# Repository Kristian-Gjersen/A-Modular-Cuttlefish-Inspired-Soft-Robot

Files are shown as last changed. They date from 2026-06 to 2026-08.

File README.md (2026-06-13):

# CUTTLE-DROID

<div align="center">
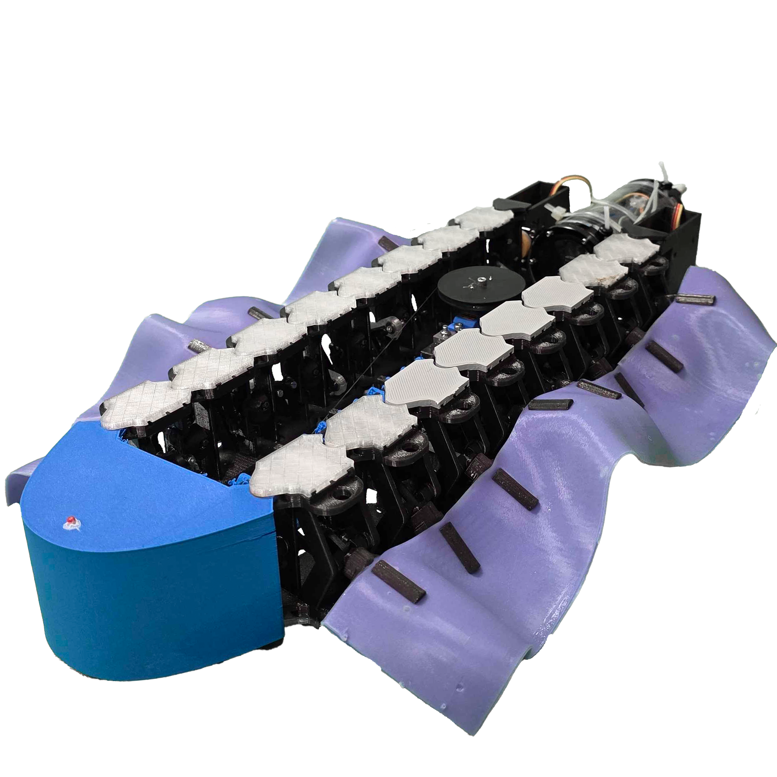
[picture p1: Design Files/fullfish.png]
  
</div>

C.U.T.T.L.E.-D.R.O.I.D.: Cuttlefish-Inspired Underwater Technology for Terrain Locomotion &amp; Exploration – Drone Robot for Ocean Inspection &amp; Discovery (Cuttle-Droid)

This repository contains the control code, setup code, 3D STL files and further supplementary used for the development of the **Cuttle-Droid** - a modular cuttlefish bio-inspired soft robot that mimics undulating wave-like motion for locomotion.

## Repository Structure

```
A-Modular-Cuttlefish-Inspired-Soft-Robot/
│
├── Design-Files/                    # Mechanical design files
│   ├── Mold/                        # STL files for casting fin
│   └── Robot/                       # STL files for the robot
│       └──Assembly-Guide/           # PDF guide on robot assembly
│
└── Robot-Control-Code/              # Arduino code for the main robot controller and pyhon code for remote control
    ├── RobotControlCode.ino         # Main controller logic For the robot
    ├── RobotRemoteController.py     # Remote controller script for manual steering
    └── Force_Test.py                # Python code for remotely controlling the force tests.
```

## Hardware Requirements
 - ESP32C3 microcontroller
 - Motor drivers and actuators
 - loadcell force sensor
 - hotspot or wifi access

## Software Requirements
- [Arduino IDE](https://www.arduino.cc/en/software)
- Python 3.11+ with packages:
    - `matplotlib`, `serial`, `keyboard`, `csv`, `time`, `socket`, `numpy`, `os`, `nidaqmx`

## Design Files

### Robot Parts
- All STL files for robot assembly located in `Design-Files/Robot`
- Guide for robot assembly and part count located in `Design-Files/Robot/Assembly-Guide`

### Mold
- STL files for Mold for fin casting found in `Design-Files/Mold`

## Code files
- `RobotControlCode.ino` contains the code uploaded to the robot. This code automatically start connecting to the provided hotspot and awaits requests for actuator inputs.
- `RobotRemoteController.py` contains the controller code for the controlling laptop. This code will start searching for ESP32 on the hotspot and once connected it will allow for sending inputs to control the actuators on the robot. Always turn on the robot before starting this script. The controls works as follows:
```
W = speed up forward
S = slow down
A/D = soft turn left and right
Q/E = servo steering left and right
Z/C = differential turn left and right
SPACE = stop
```
- `Force_Test.py` contains the script used for doing force test readings on the robot. It sets up the ESP32, Daq, and Arduino to automatically perform the test that is selected. It will handle timing and duty cycle inputs to the robot. Always have the robot turned on before performing force test.

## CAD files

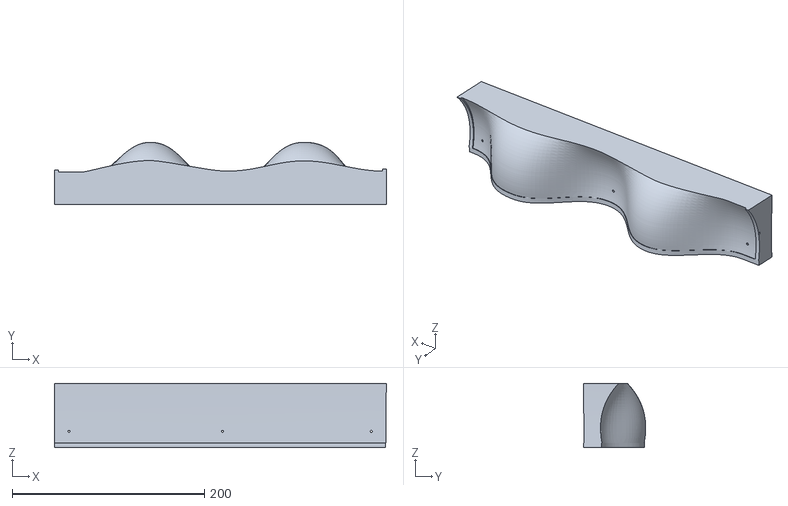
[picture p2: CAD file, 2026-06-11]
Design Files/Mold/Mold 1.stl
345.8 x 65.0 x 67.0

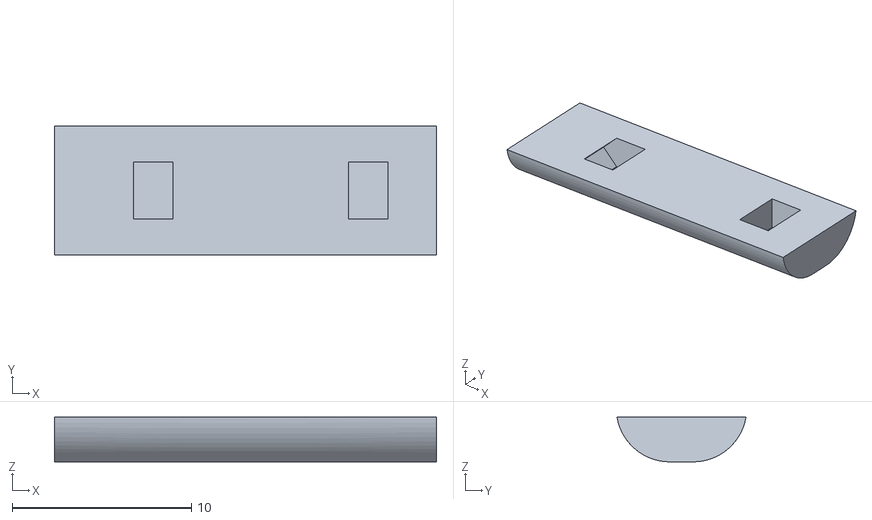
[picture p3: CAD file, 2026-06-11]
Design Files/Robot/Pocket Fin Clamp.stl
21.3 x 7.20 x 2.50

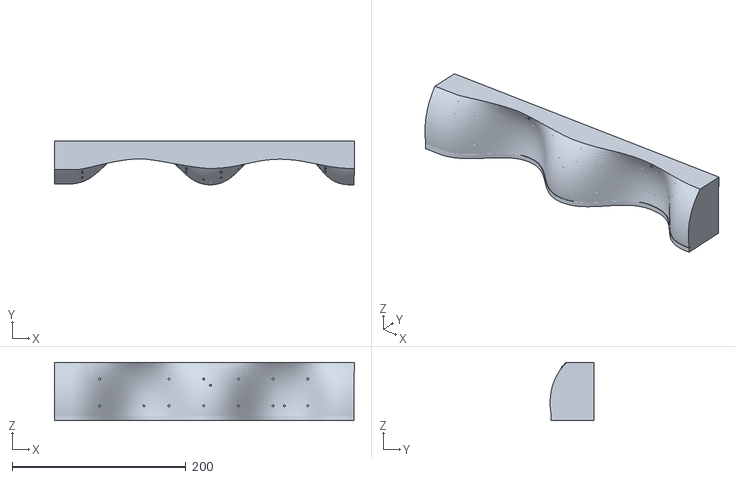
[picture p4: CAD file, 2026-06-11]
Design Files/Mold/Mold 2.stl
345.8 x 50.4 x 67.0

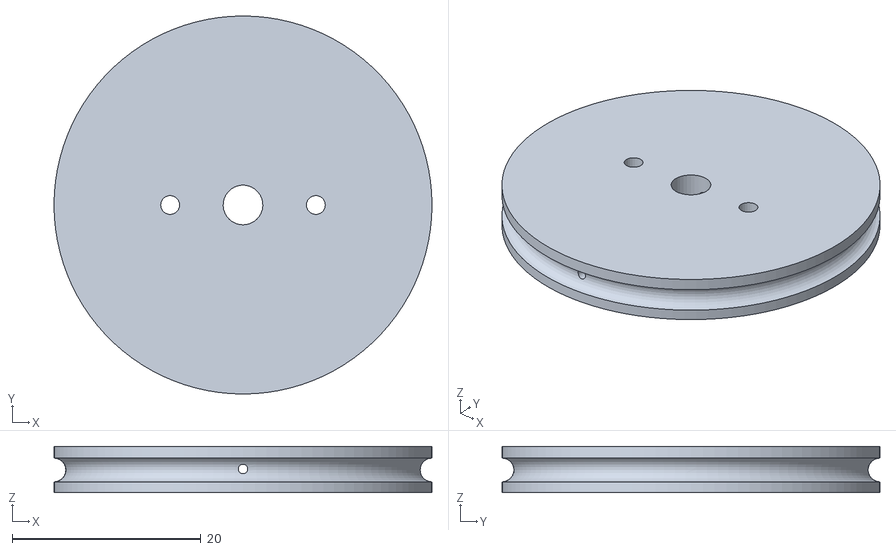
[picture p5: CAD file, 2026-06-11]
Design Files/Robot/Thread Holder.stl
40.0 x 40.0 x 4.90

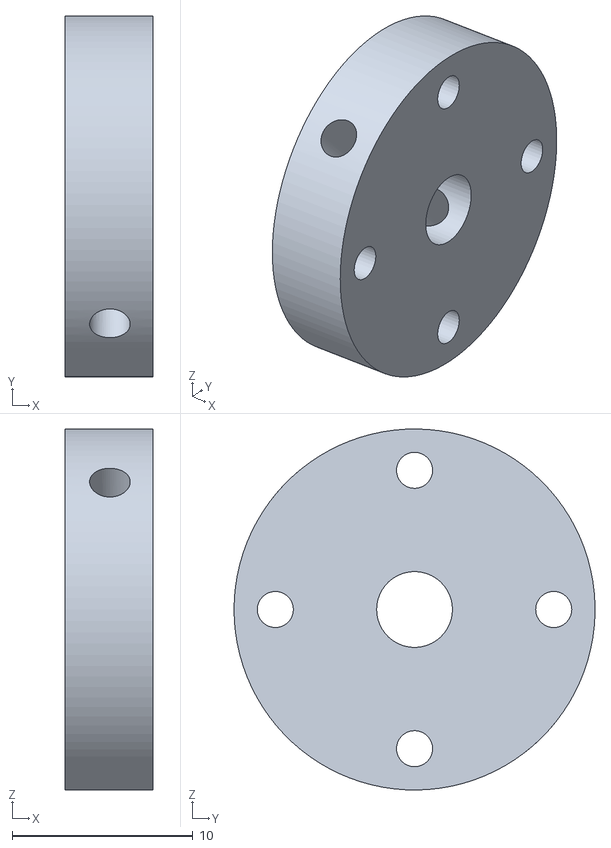
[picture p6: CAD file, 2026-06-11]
Design Files/Robot/Servo Ball Joint.stl
4.90 x 20.0 x 20.0

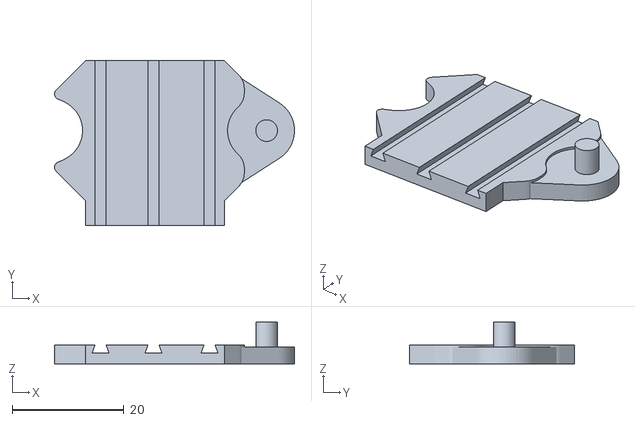
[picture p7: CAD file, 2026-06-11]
Design Files/Robot/Clamp.stl
43.0 x 29.6 x 7.50

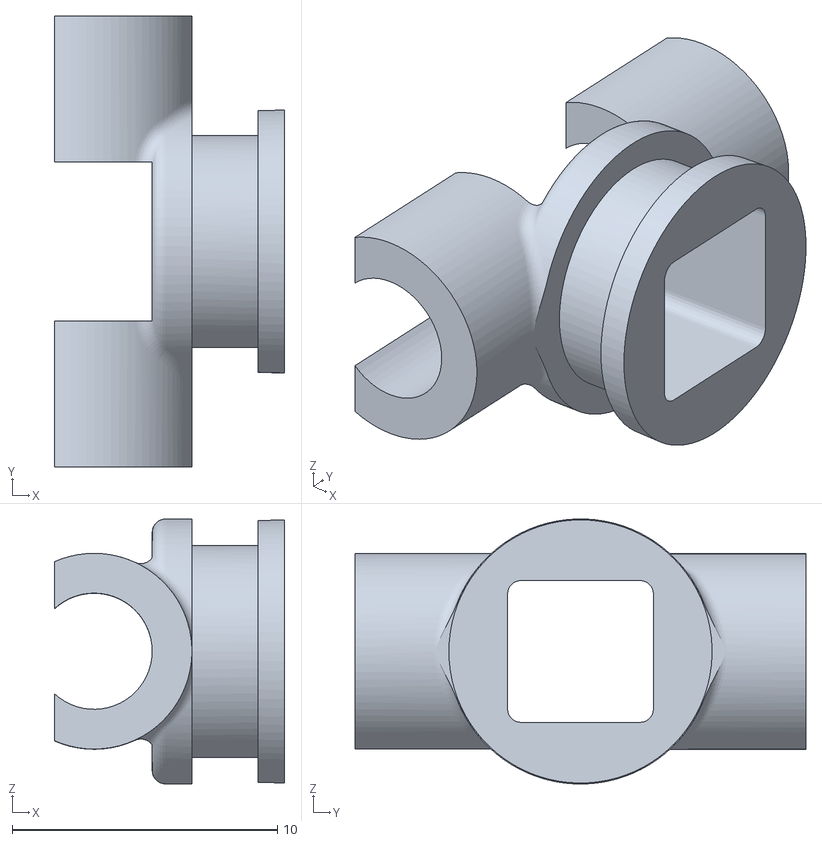
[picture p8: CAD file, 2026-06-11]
Design Files/Robot/Pocket Sleeve Joint.stl
8.69 x 17.0 x 10.00

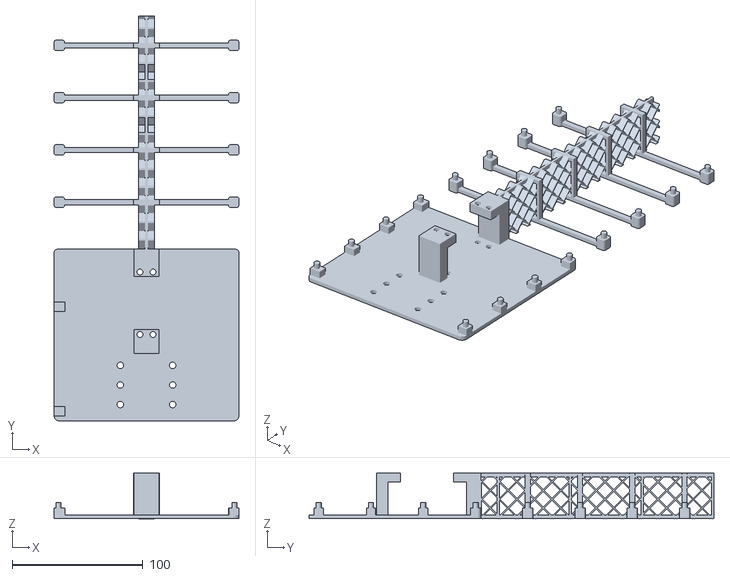
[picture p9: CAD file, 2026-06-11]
Design Files/Robot/Spine.stl
141.5 x 310.0 x 35.2

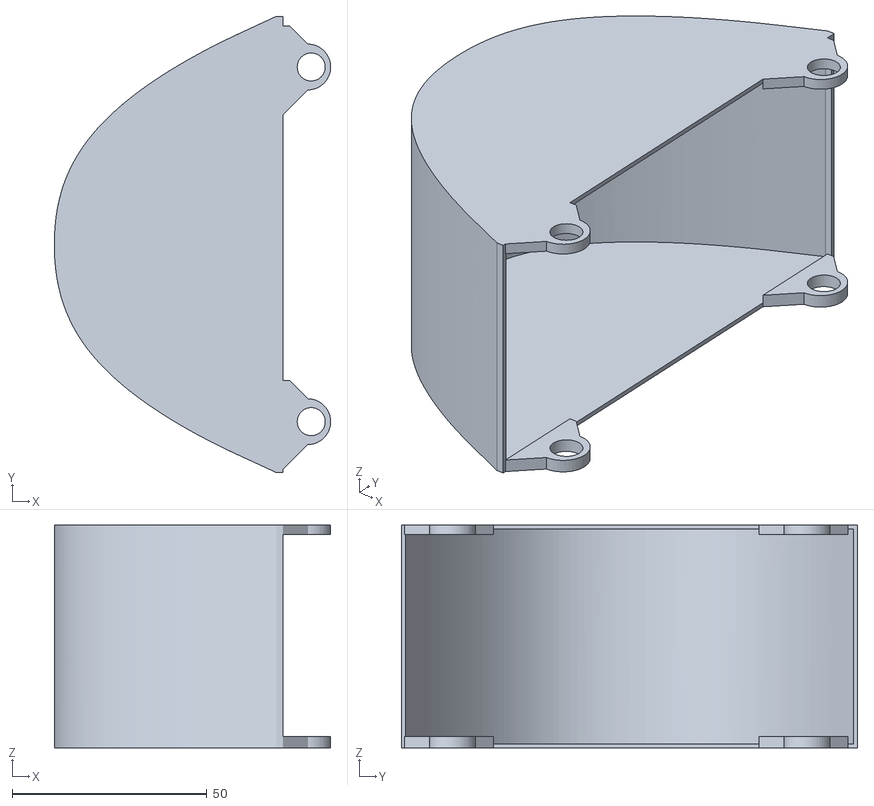
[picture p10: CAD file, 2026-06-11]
Design Files/Robot/Head.stl
70.9 x 117.0 x 57.2

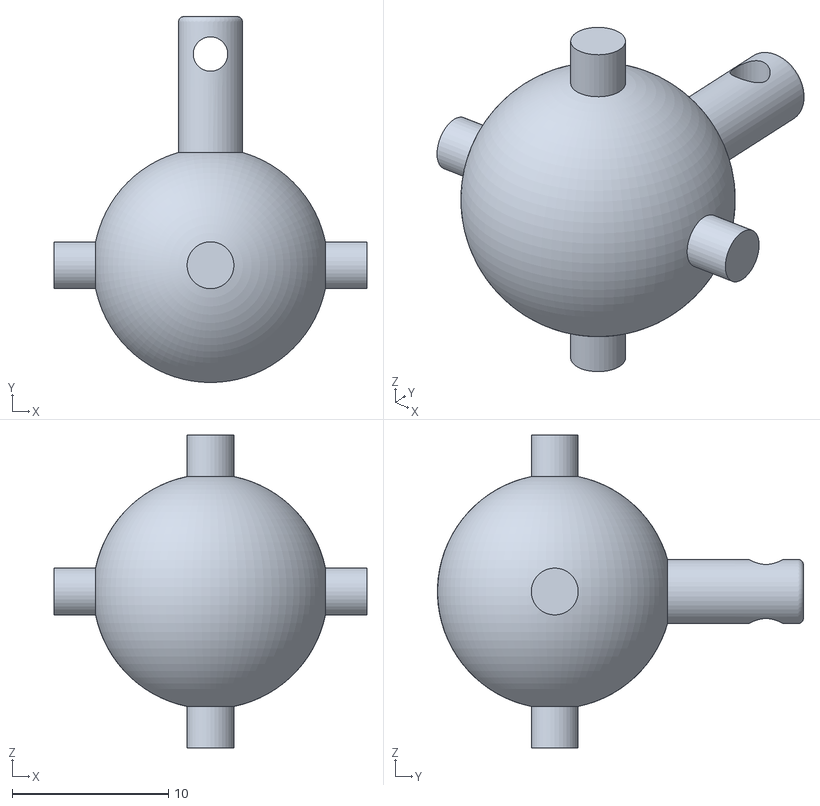
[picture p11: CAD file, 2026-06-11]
Design Files/Robot/Camshaft Ball.stl
20.0 x 23.4 x 20.0

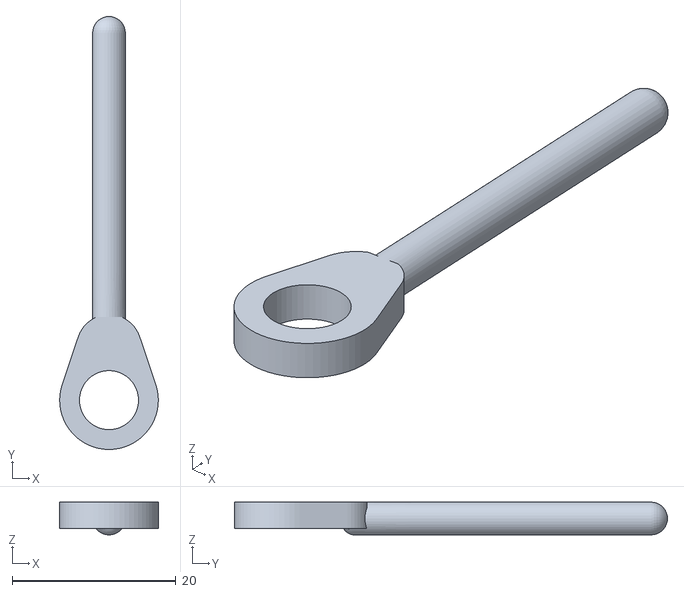
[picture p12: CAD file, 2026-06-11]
Design Files/Robot/Rod.stl
12.0 x 52.8 x 4.00

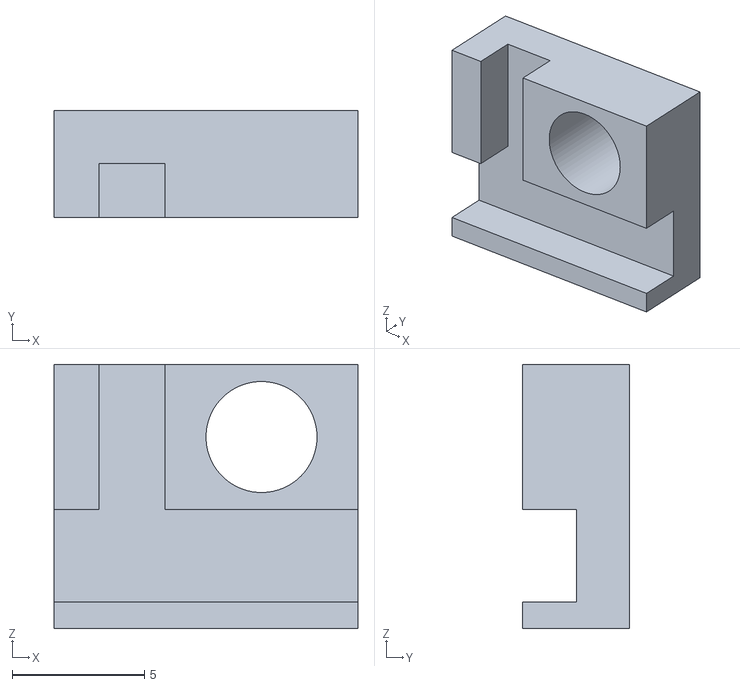
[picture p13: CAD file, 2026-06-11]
Design Files/Robot/Tendon Holder Part 1.stl
11.5 x 4.05 x 10.0

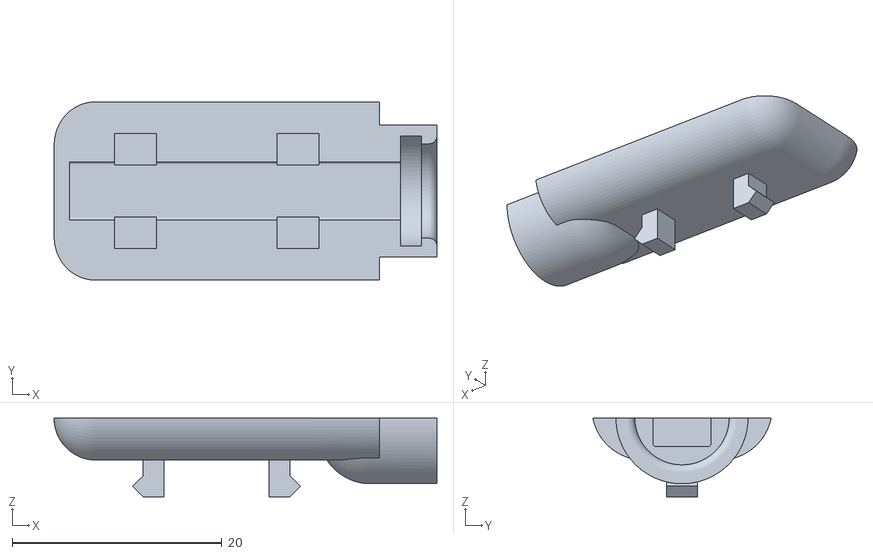
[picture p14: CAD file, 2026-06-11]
Design Files/Robot/Pocket Top.stl
36.5 x 17.0 x 7.50

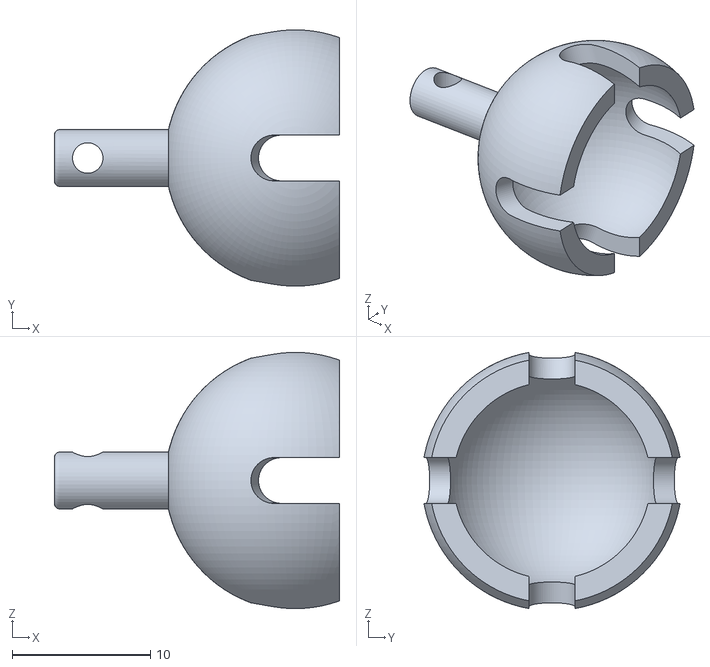
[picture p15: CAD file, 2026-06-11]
Design Files/Robot/Camshaft Cup.stl
20.6 x 18.5 x 18.5

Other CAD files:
Design Files/Robot/Motor Holder.stl
Design Files/Robot/Motor Clamp Top.stl
Design Files/Robot/Camshaft Spacer.stl
Design Files/Robot/Pocket Bottom.stl
Design Files/Robot/Camshaft Bottom.stl
Design Files/Robot/Clamp Mirrored.stl
Design Files/Robot/Dovetail Pin.stl
Design Files/Robot/Frame.stl
Design Files/Robot/Motor Clamp Bottom.stl
Design Files/Robot/Tendon Holder Part 2.stl

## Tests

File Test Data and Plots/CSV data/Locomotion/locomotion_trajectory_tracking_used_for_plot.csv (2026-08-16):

 | mass_A
x | y
3.591918E-1 | -1.433480E-1
3.635274E-1 | -1.420296E-1
3.674668E-1 | -1.415576E-1
3.711204E-1 | -1.419468E-1
3.733004E-1 | -1.457875E-1
3.748996E-1 | -1.497346E-1
3.763999E-1 | -1.533793E-1
3.784218E-1 | -1.570687E-1
3.804790E-1 | -1.590580E-1
3.815482E-1 | -1.605636E-1
3.828061E-1 | -1.604650E-1
3.831343E-1 | -1.597268E-1
3.832537E-1 | -1.589973E-1
3.834170E-1 | -1.590138E-1
3.833947E-1 | -1.581930E-1
3.832934E-1 | -1.574010E-1
3.835377E-1 | -1.576304E-1
3.836087E-1 | -1.571106E-1
3.837571E-1 | -1.564713E-1
3.836312E-1 | -1.560985E-1
3.838335E-1 | -1.548110E-1
3.849036E-1 | -1.535936E-1
3.855755E-1 | -1.534003E-1
3.857027E-1 | -1.525668E-1
3.864230E-1 | -1.515214E-1
3.876199E-1 | -1.508585E-1
3.891273E-1 | -1.488150E-1
3.907098E-1 | -1.477049E-1
3.919873E-1 | -1.478055E-1
3.936036E-1 | -1.472316E-1
3.966411E-1 | -1.460089E-1
3.994982E-1 | -1.451338E-1
4.025773E-1 | -1.426647E-1
4.059409E-1 | -1.416462E-1
4.094240E-1 | -1.384673E-1
4.122796E-1 | -1.357946E-1
4.150008E-1 | -1.336879E-1
4.177148E-1 | -1.332203E-1
4.200919E-1 | -1.338718E-1
4.223962E-1 | -1.357766E-1
4.248015E-1 | -1.362407E-1
4.263255E-1 | -1.374444E-1
4.276979E-1 | -1.377233E-1
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

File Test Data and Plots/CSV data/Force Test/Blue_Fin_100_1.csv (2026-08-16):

time | voltage | force_N
0.000000000000000000e+00 | 3.627415765076875687e-01 | 1.613554921375166540e-01
1.000000000000000021e-03 | 3.470953628420829773e-01 | 1.543957095550839709e-01
2.000000000000000042e-03 | 3.366645537316799164e-01 | 1.497558545001288766e-01
3.000000000000000062e-03 | 3.262337446212768555e-01 | 1.451159994451737545e-01
4.000000000000000083e-03 | 3.158029355108737946e-01 | 1.404761443902186602e-01
5.000000000000000104e-03 | 3.105875309556722641e-01 | 1.381562168627410991e-01
6.000000000000000125e-03 | 3.105875309556722641e-01 | 1.381562168627410991e-01
7.000000000000000146e-03 | 3.001567218452692032e-01 | 1.335163618077860048e-01
8.000000000000000167e-03 | 2.949413172900676727e-01 | 1.311964342803084438e-01
8.999999999999999320e-03 | 2.897259127348661423e-01 | 1.288765067528308828e-01
1.000000000000000021e-02 | 2.897259127348661423e-01 | 1.288765067528308828e-01
1.099999999999999936e-02 | 2.897259127348661423e-01 | 1.288765067528308828e-01
1.200000000000000025e-02 | 2.845105081796646118e-01 | 1.265565792253533217e-01
1.299999999999999940e-02 | 2.740796990692615509e-01 | 1.219167241703982552e-01
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

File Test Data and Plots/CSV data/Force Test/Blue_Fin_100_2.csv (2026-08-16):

time | voltage | force_N
0.000000000000000000e+00 | -6.492159701883792877e-02 | -2.887856511564265358e-02
1.000000000000000021e-03 | -8.578321523964405060e-02 | -3.815827522555285956e-02
2.000000000000000042e-03 | -1.118602380156517029e-01 | -4.975791286294062310e-02
3.000000000000000062e-03 | -1.275064516812562943e-01 | -5.671769544537327845e-02
4.000000000000000083e-03 | -1.431526653468608856e-01 | -6.367747802780593380e-02
5.000000000000000104e-03 | -1.587988790124654770e-01 | -7.063726061023860303e-02
6.000000000000000125e-03 | -1.796604972332715988e-01 | -7.991697072014880554e-02
7.000000000000000146e-03 | -2.161683291196823120e-01 | -9.615646341249167728e-02
8.000000000000000167e-03 | -2.422453518956899643e-01 | -1.077561010498794269e-01
8.999999999999999320e-03 | -2.631069701164960861e-01 | -1.170358111597896295e-01
1.000000000000000021e-02 | -2.839685883373022079e-01 | -1.263155212696998320e-01
1.099999999999999936e-02 | -3.048302065581083298e-01 | -1.355952313796100484e-01
1.200000000000000025e-02 | -3.204764202237129211e-01 | -1.425550139620427037e-01
1.299999999999999940e-02 | -3.413380384445190430e-01 | -1.518347240719528923e-01
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

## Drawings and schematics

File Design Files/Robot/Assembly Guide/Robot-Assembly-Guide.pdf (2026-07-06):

# Cuttle Bot

## User assembly manual for 8 links Cuttle bot

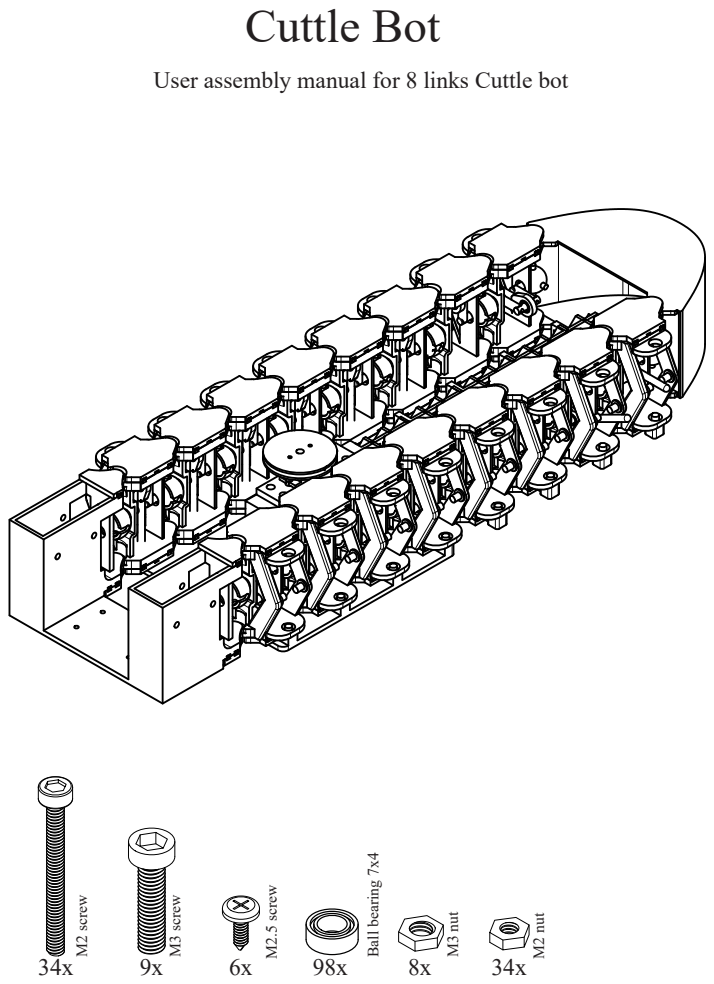
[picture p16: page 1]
34x M² screw; M3 screw; M2.5 screw; Ball bearing 7x4; M3 nut; M2 nut

# One 8 Link Propulsion Module assembly

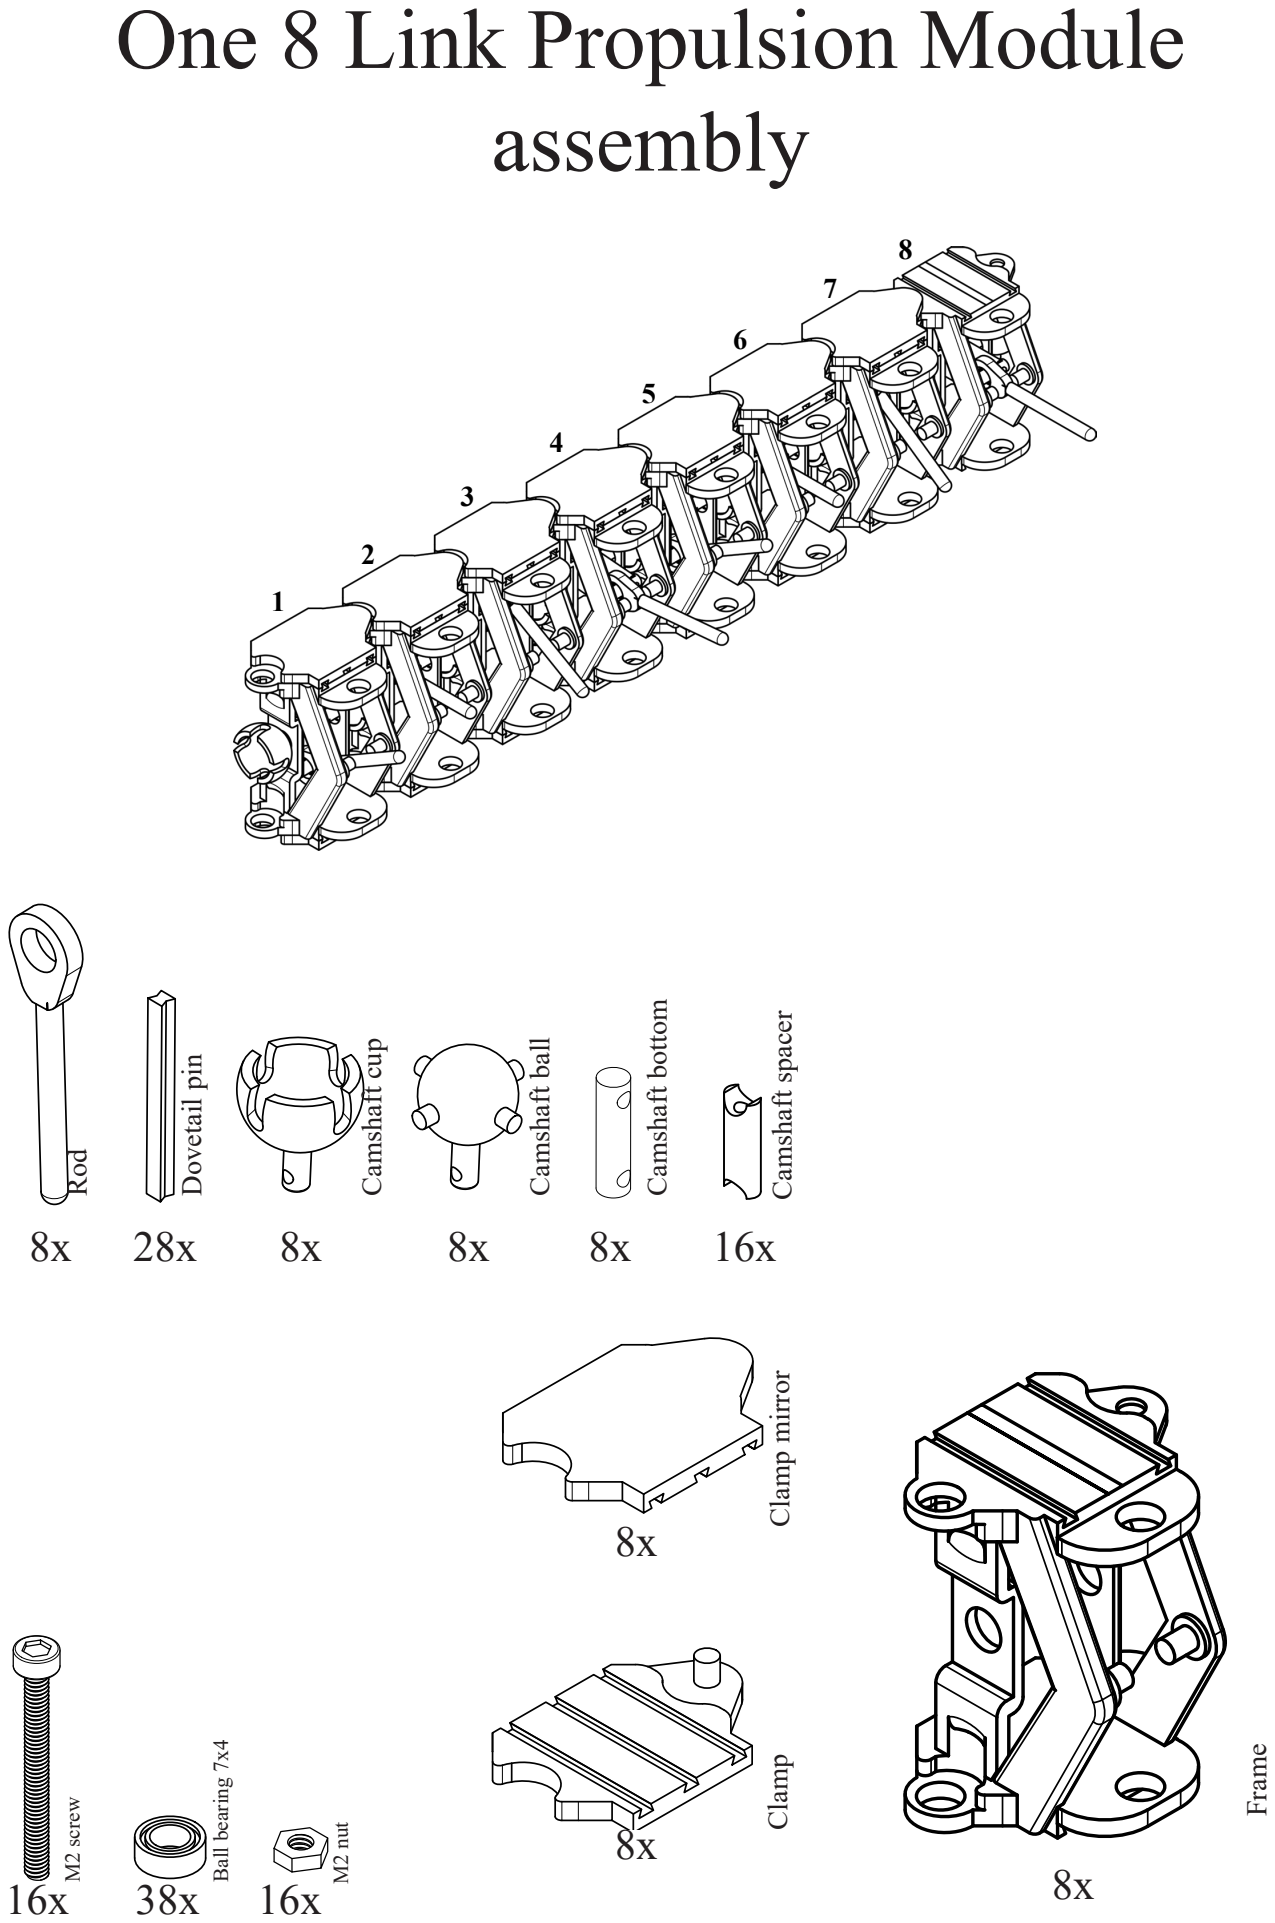
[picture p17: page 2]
Created by; Document type; Approved by; Document status; Camshaft Bottom; Rod; Dovetail pin; Camshaft cup; Camshaft ball; Camshaft bottom; Camshaft spacer; 16x 38x 16x M² screw; Ball bearing 7x4; M2 nut; Frame

Rikke Thastum Joergensen

Title DWG No.

Rev. Date of issue

Clamp Clamp mirror

1 | 2

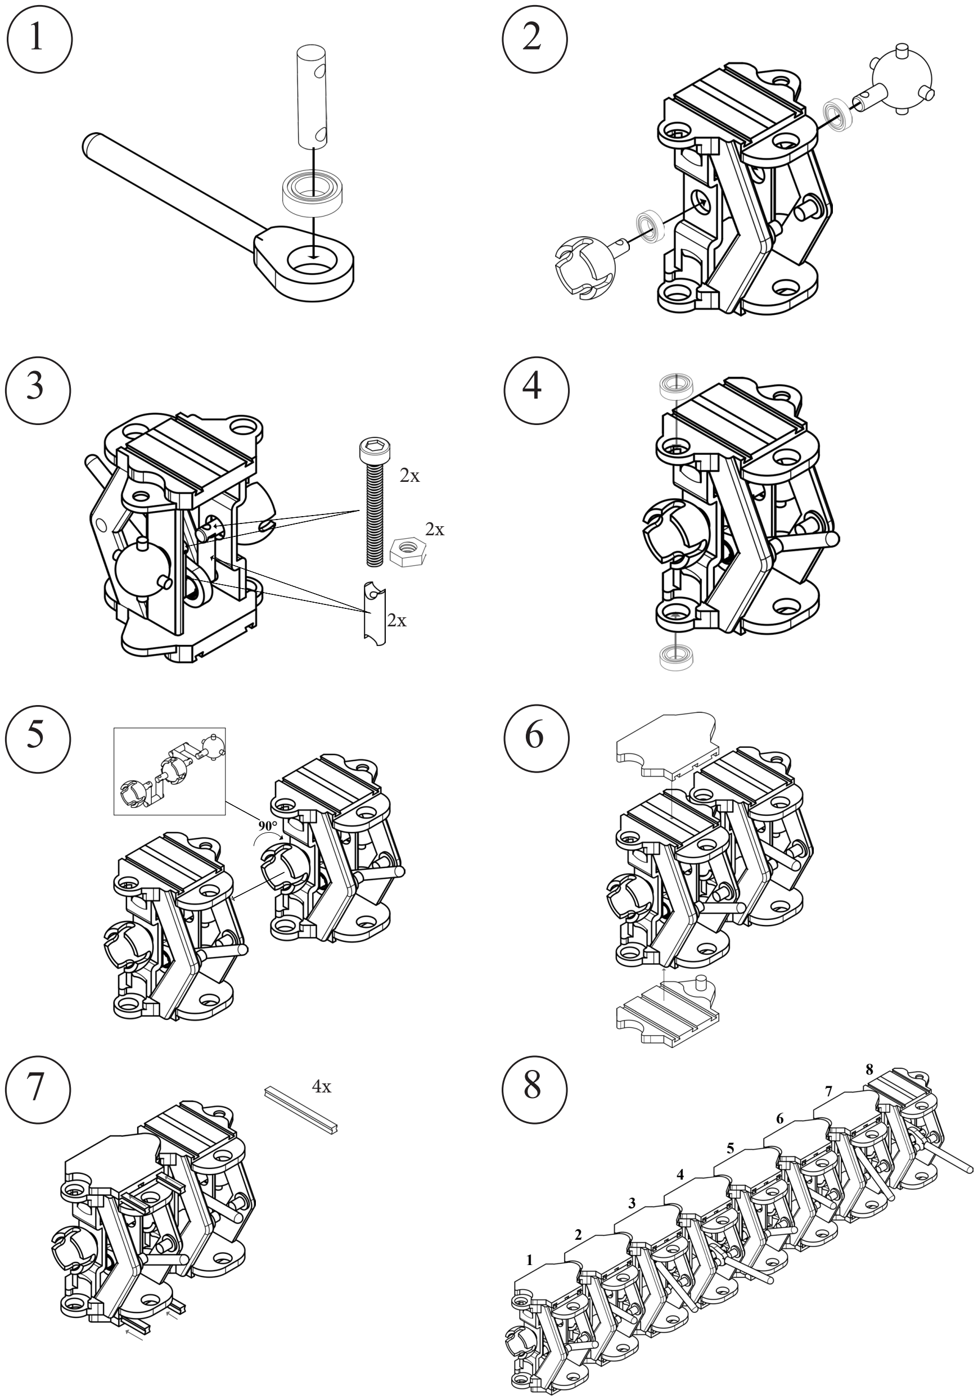
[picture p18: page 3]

90°

2x

2x

4x

3 | 4
5 | 6

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
# Steering Module assembly

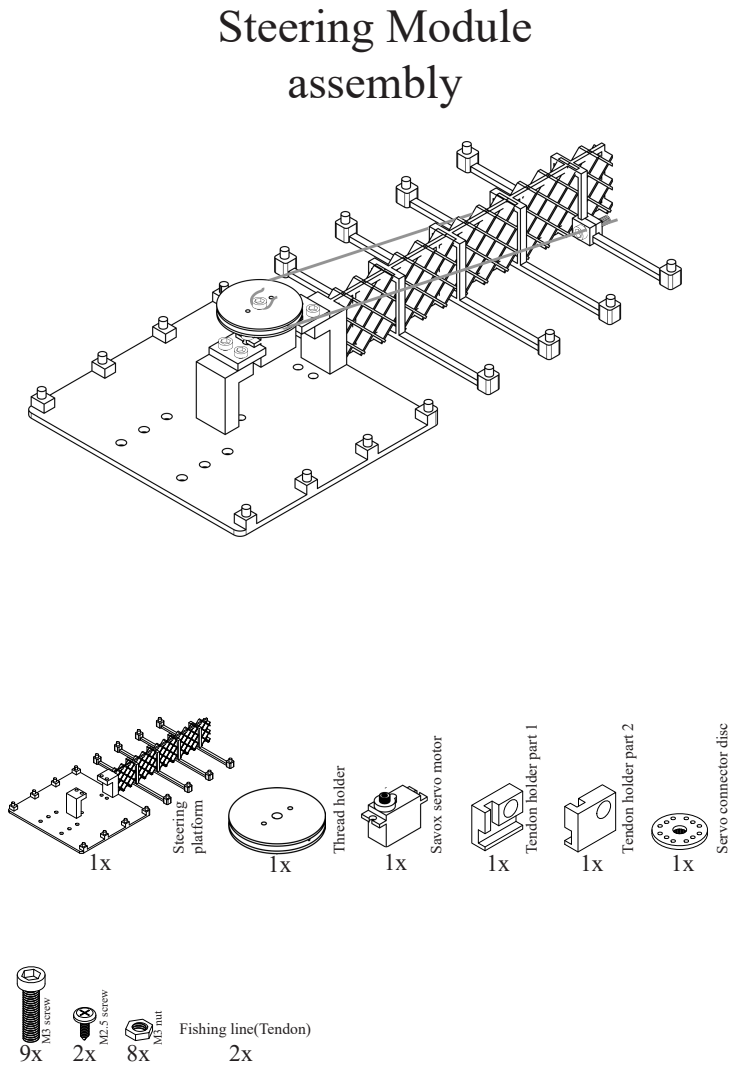
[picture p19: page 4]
Steering; platform; Thread holder; M3 screw; M2.5 screw

Tendon holder part 1

Tendon holder part 2

Servo connector disc

Savox servo motor

M3 nut
Fishing line(Tendon)

1

2

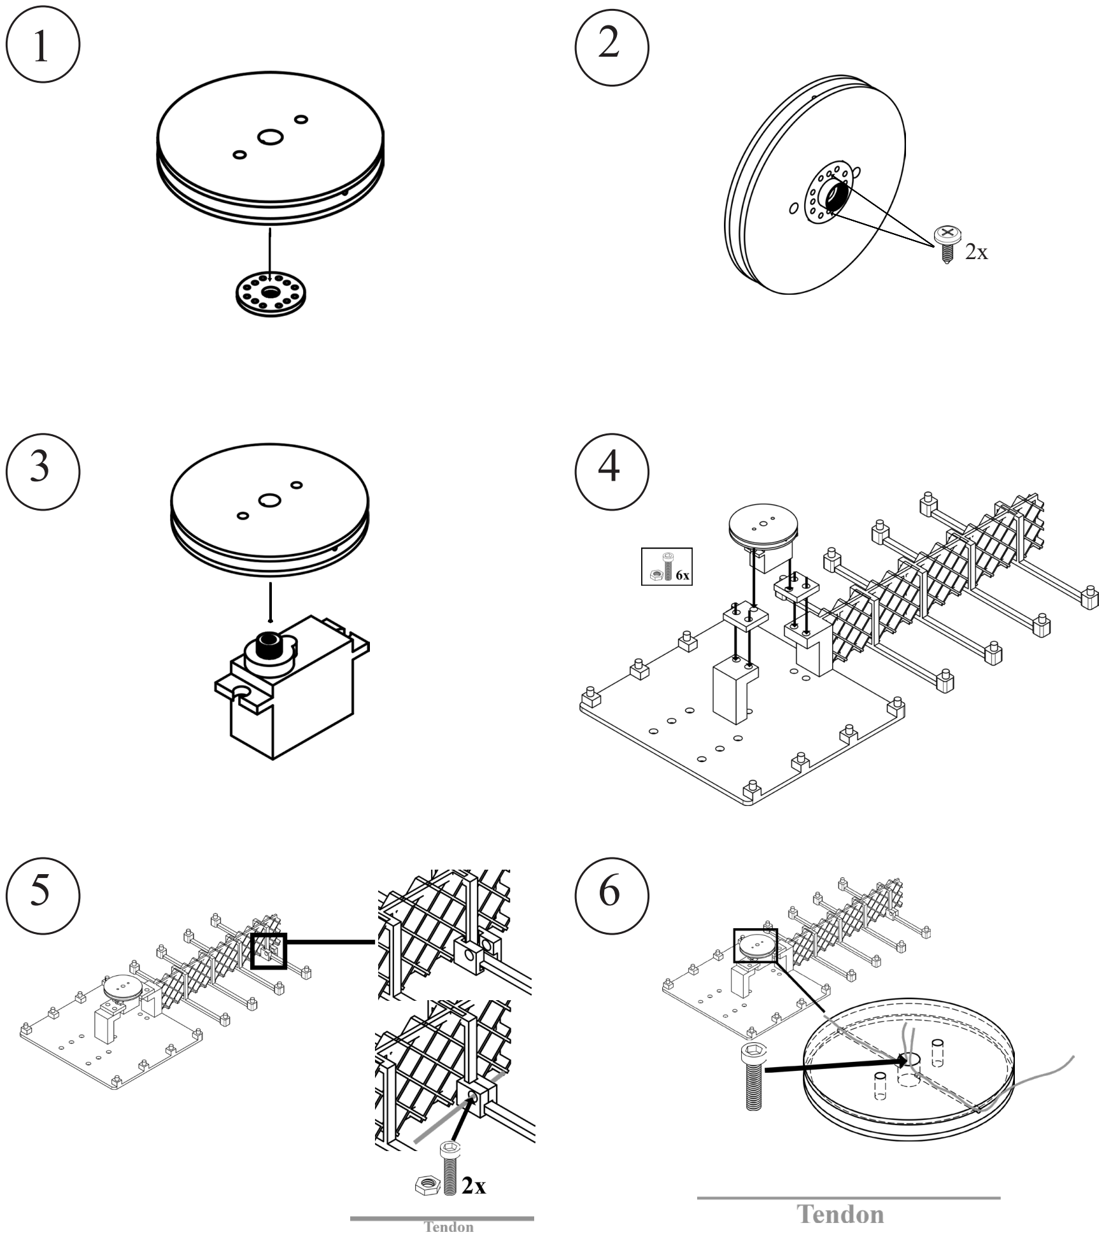
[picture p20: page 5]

3

4

5

6

2x

# Camshaft Motor Module assembly

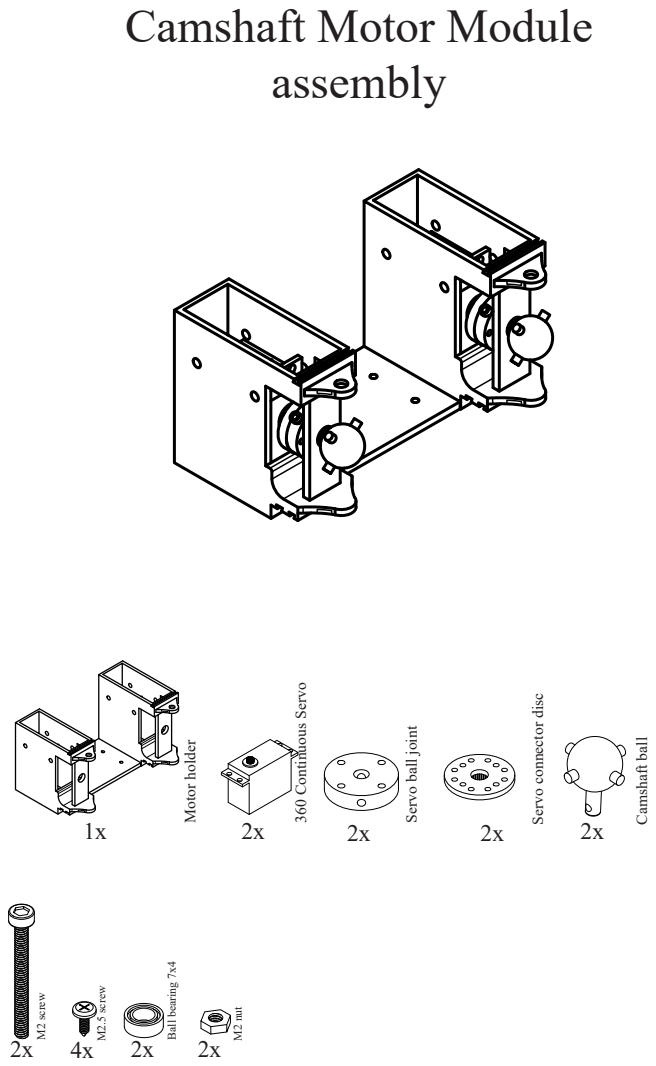
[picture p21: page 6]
2x M² screw; Ball bearing 7x4; M2 nut; Motor holder; 360 Continuous Servo; Created by; Document type; M2.5 screw

Rikke Thastum Joergensen Camshaft ball

Servo connector disc

Servo ball joint

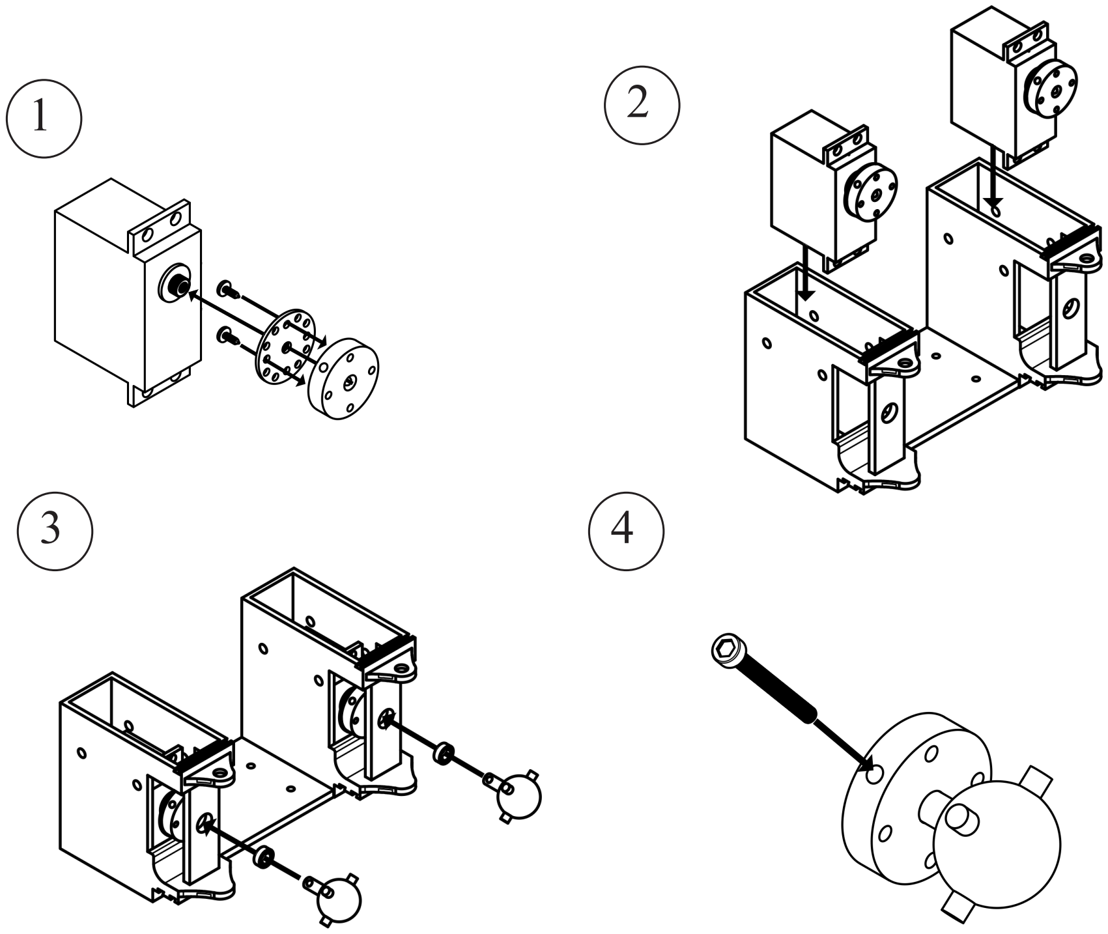
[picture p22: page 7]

1

2

3

4

# Complete assembly

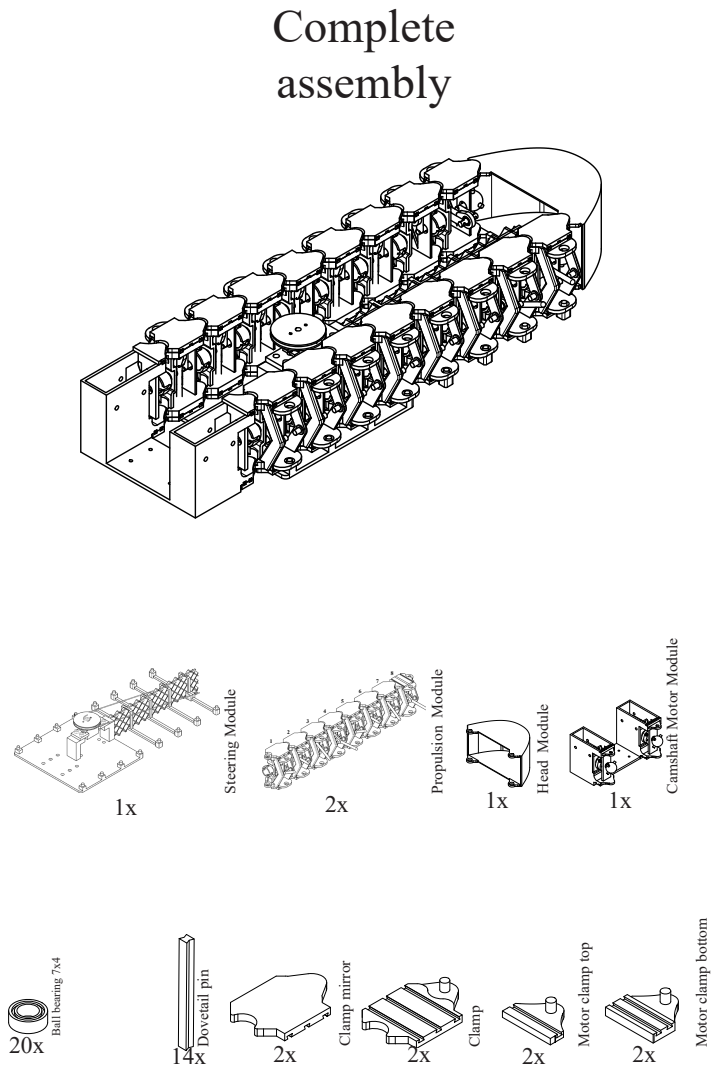
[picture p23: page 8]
Ball bearing 7x4; Steering Module; Propulsion Module; Head Module; Clamp mirror; Clamp; Dovetail pin

Camshaft Motor Module

Motor clamp bottom

Motor clamp top

1 | 2

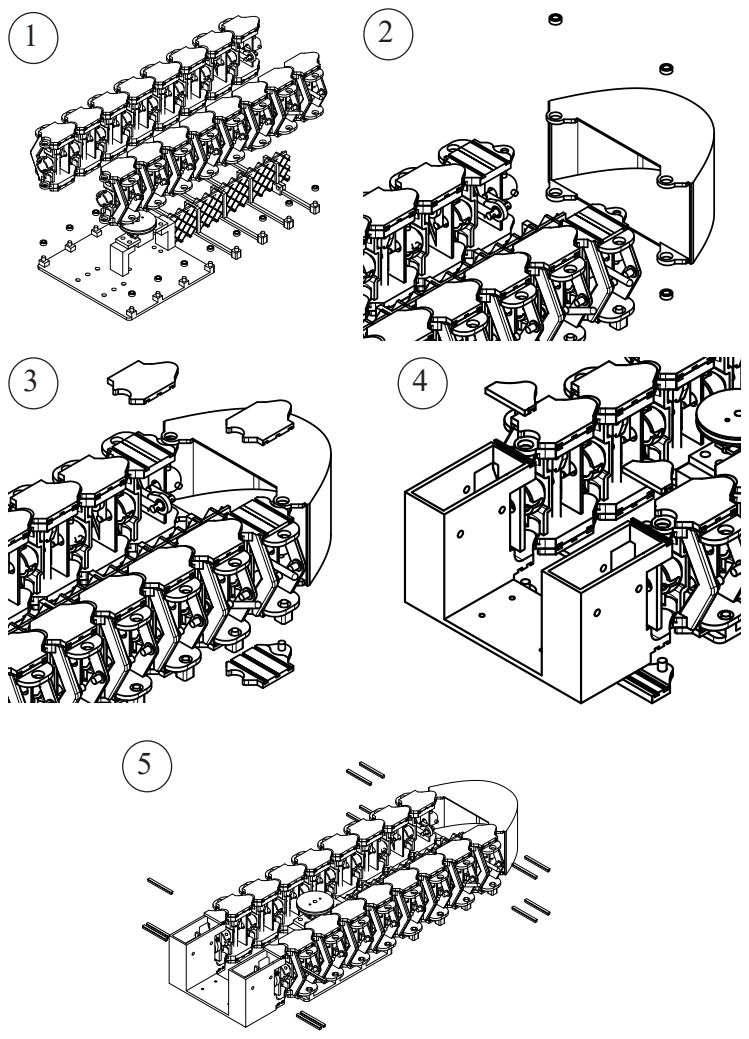
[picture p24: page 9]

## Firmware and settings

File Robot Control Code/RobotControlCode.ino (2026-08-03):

#include <WiFi.h>
#include <Wire.h>
#include <Adafruit_PWMServoDriver.h>

// WiFi
// ----
// Setup a costum hotspot and provide ssid and password
// Make sure that the laptop is connected to the same hotspot
const char* ssid = "WiFi-SSID";
const char* password = "WiFi-Password";

WiFiServer server(80);

// MOTOR PINS
// ----------
#define DIR2 7   // D0
#define PWM2 6   // D1
#define PWM1 5   // D2
#define DIR1 1   // D3

// PCA9685
// -------
Adafruit_PWMServoDriver pwm = Adafruit_PWMServoDriver(0x40);

// Servo settings
#define SERVOMIN  800
#define SERVOMAX  2200
#define SERVO_CHANNEL 12
#define SERVO_FREQ 240
#define SERVO_CENTER_ANGLE 50

int currentSpeed = 0;
const int maxSpeed = 150;
const int rampRate = 2;

int driveMode = 0;
int servoOffset = 0;

void setup() {
  Serial.begin(115200);

  // Motor pins
  pinMode(DIR1, OUTPUT);
  pinMode(PWM1, OUTPUT);
  pinMode(DIR2, OUTPUT);
  pinMode(PWM2, OUTPUT);

  stopMotors();

  // Setup I2C manually for ESP32
  Wire.begin(8, 9); // SDA=8, SCL=9

  pwm.begin();
  pwm.setPWMFreq(SERVO_FREQ);
  setSteeringOffset(0);

  delay(500);

  // WiFi
  WiFi.mode(WIFI_STA);
  WiFi.begin(ssid, password);
  Serial.print("Connecting");
  while (WiFi.status() != WL_CONNECTED) {
    delay(500);
    Serial.print(".");
  }
  Serial.println("\nConnected!");
  Serial.print("IP: ");
  Serial.println(WiFi.localIP());

  server.begin();
  Serial.println("SERVER STARTED");
}

void loop() {
  WiFiClient client = server.available();

  if (client) {
    Serial.println("CLIENT CONNECTED");

    while (client.connected()) {
      if (client.available()) {
        String cmd = client.readStringUntil('\n');
        cmd.trim();
        Serial.println("Received: " + cmd);

        handleCommand(cmd);
        updateOutputs();
      }
    }

    stopMotors();
    client.stop();
    Serial.println("CLIENT DISCONNECTED");
  }
}

void handleCommand(String cmd) {
  if (cmd.startsWith("DRIVE:")) {
    int firstComma = cmd.indexOf(',');
    int secondComma = cmd.indexOf(',', firstComma + 1);

    if (firstComma == -1 || secondComma == -1) {
      return;
    }

    int speedDelta = cmd.substring(6, firstComma).toInt();
    driveMode = cmd.substring(firstComma + 1, secondComma).toInt();
    servoOffset = cmd.substring(secondComma + 1).toInt();

    currentSpeed += speedDelta;
    currentSpeed = constrain(currentSpeed, 0, maxSpeed);

  } else if (cmd == "STOP") {
    currentSpeed = 0;
    driveMode = 0;
    servoOffset = 0;
    stopMotors();
    setSteeringOffset(0);
  }
}

void updateOutputs() {
  setSteeringOffset(servoOffset);
  driveMotorsByMode(driveMode);
  delay(rampRate);
}

// MOTOR FUNCTIONS
// ---------------

void driveMotorsByMode(int mode) {
  currentSpeed = map(currentSpeed, 0, 100, 0, 255);
  switch (mode) {
    case -1:
      // Soft left: motor 1 off, motor 2 forward.
      motor1Stop();
      motor2Forward(currentSpeed);
      break;

    case 1:
      // Soft right: motor 1 forward, motor 2 off.
      motor1Forward(currentSpeed);
      motor2Stop();
      break;

    case -2:
      // Differential left: motor 1 backward, motor 2 forward.
      motor1Backward(currentSpeed);
      motor2Forward(currentSpeed);
      break;

    case 2:
      // Differential right: motor 1 forward, motor 2 backward.
      motor1Forward(currentSpeed);
      motor2Backward(currentSpeed);
      break;

    case 0:
      // Normal forward drive.
      motor1Forward(currentSpeed);
      motor2Forward(currentSpeed);
      break;
  }
}

void motor1Forward(int speed) {
  digitalWrite(DIR1, LOW);
  analogWrite(PWM1, speed);
}

void motor1Backward(int speed) {
  digitalWrite(DIR1, HIGH);
  analogWrite(PWM1, speed);
}

void motor2Forward(int speed) {
  digitalWrite(DIR2, HIGH);
  analogWrite(PWM2, speed);
}

void motor2Backward(int speed) {
  digitalWrite(DIR2, LOW);
  analogWrite(PWM2, speed);
}

void motor1Stop() {
  analogWrite(PWM1, 0);
}

void motor2Stop() {
  analogWrite(PWM2, 0);
}

void stopMotors() {
  motor1Stop();
  motor2Stop();
}

// SERVO FUNCTION
// --------------

void setSteeringOffset(int offset) {
  int angle = constrain(SERVO_CENTER_ANGLE + offset, 0, 180);
  int pulse = map(angle, 0, 100, SERVOMIN, SERVOMAX);
  pwm.setPWM(SERVO_CHANNEL, 0, pulse);
}

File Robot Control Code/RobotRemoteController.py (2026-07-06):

import socket
import keyboard
import time
import csv
from datetime import datetime

PORT = 80
LOG_FILE = "commandlog.csv"

# Tuning values
SPEED_STEP = 5       # How much W/S changes current speed per command tick
SEND_INTERVAL = 0.05 # Seconds between commands
SERVO_ANGLE = 50     # Servo offset sent to robot: -15, 0, or +15 degrees

# Drive mode values sent to the ESP:
#   0  = both motors forward at currentSpeed
#  -1  = soft left:  motor 1 off, motor 2 forward
#   1  = soft right: motor 1 forward, motor 2 off
#  -2  = differential left:  motor 1 backward, motor 2 forward
#   2  = differential right: motor 1 forward, motor 2 backward


def get_laptop_ip():
    temp = socket.socket(socket.AF_INET, socket.SOCK_DGRAM)
    try:
        temp.connect(("8.8.8.8", 80))
        return temp.getsockname()[0]
    finally:
        temp.close()


def find_esp():
    laptop_ip = get_laptop_ip()
    subnet = ".".join(laptop_ip.split(".")[:3])

    print("Laptop IP:", laptop_ip)
    print(f"Searching for ESP on {subnet}.x ...")

    for i in range(1, 255):
        ip = f"{subnet}.{i}"

        if ip == laptop_ip:
            continue

        try:
            test = socket.create_connection((ip, PORT), timeout=0.5)
            test.close()
            print("Found ESP:", ip)
            return ip
        except Exception:
            pass

    return None


ESP_IP = find_esp()

if ESP_IP is None:
    print("Could not find ESP")
    exit()

s = socket.create_connection((ESP_IP, PORT), timeout=3)
s.settimeout(None)

log_file = open(LOG_FILE, "a", newline="")
csv_writer = csv.writer(log_file)

if log_file.tell() == 0:
    csv_writer.writerow(["timestamp", "command"])

print("Connected to:", ESP_IP)
print("Controls:")
print("  W = speed up forward")
print("  S = slow down")
print("  A/D = soft turn by turning off one drive motor")
print("  Q/E = servo steering -15/+15 degrees")
print("  Z/C = differential turn")
print("  SPACE = stop")


def send(cmd):
    try:
        s.sendall((cmd + "\n").encode())

        csv_writer.writerow([
            datetime.now().isoformat(timespec="seconds"),
            cmd,
        ])
        log_file.flush()

    except Exception as e:
        print("Error sending data:", e)


try:
    while True:
        speed_delta = 0
        drive_mode = 0
        servo_offset = 0

        # Speed control: W increases current forward speed, S decreases it.
        if keyboard.is_pressed("w"):
            speed_delta = SPEED_STEP
        elif keyboard.is_pressed("s"):
            speed_delta = -SPEED_STEP

        # Soft turn: one motor off, the other motor powered by currentSpeed.
        # I used A/D here because E is used for servo steering below.
        if keyboard.is_pressed("a"):
            drive_mode = -1
        elif keyboard.is_pressed("d"):
            drive_mode = 1

        # Differential turn: one motor forward, the other backward.
        if keyboard.is_pressed("z"):
            drive_mode = -2
        elif keyboard.is_pressed("c"):
            drive_mode = 2

        # Servo steering: centered unless Q or E is held.
        if keyboard.is_pressed("q"):
            servo_offset = -SERVO_ANGLE
        elif keyboard.is_pressed("e"):
            servo_offset = SERVO_ANGLE

        if keyboard.is_pressed("space"):
            send("STOP")
            time.sleep(0.1)
            continue

        send(f"DRIVE:{speed_delta},{drive_mode},{servo_offset}")
        time.sleep(SEND_INTERVAL)

finally:
    s.close()
    log_file.close()

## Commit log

2026-06-11 Uploaded STL Files
    [Camshaft Ball.stl, Camshaft Bottom.stl, Camshaft Cup.stl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]
2026-06-11 Updated STL Files
    [Spine TPU layer.stl, Spine Without TPU layer.stl]
2026-07-05 Update servo steering control instructions
2026-07-05 Adjust servo settings for improved control
2026-07-06 Fix motor1 direction & mode; update servo note
    Make motor1 direction logic consistent and explicit: change the switch default to case 0 for normal forward drive and invert DIR1 writes so motor1Forward() sets DIR1 LOW and motor1Backward() sets DIR1 HIGH to correct motor polarity. Also update the SERVO_ANGLE comment to reflect offsets of -15/0/+15 degrees (value unchanged) to clarify intended servo behavior.
    [RobotControlCode.ino, RobotRemoteController.py]
2026-07-06 Include duty params in DRIVE command
    Append ",0,0" to the send_esp DRIVE calls in Force_Test.py (two locations). This makes the DRIVE command include the extra duty-cycle/parameter fields (explicit zeros) so the command matches the expe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
2026-07-06 Update Robot Assembly Guide PDF
    Replace Robot-Assembly-Guide.pdf under Design Files/Robot/Assembly Guide with an updated binary version. Keeps the assembly documentation current by updating the PDF file.
2026-08-03 Fix indentation in driveMotorsByMode function
    [RobotControlCode.ino]
2026-08-16 Script and Data for Tests and Plots
    [Blue_Fin_100_1.csv, Blue_Fin_100_2.csv, Blue_Fin_100_3.csv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]
2026-08-16 Add voltage-to-force conversion & parsing
    Introduce load-cell calibration constants and a voltage_to_force() helper to convert measured voltage to Newtons (including distance scaling). Update load_trials() to accept files with either a 'voltage' or 'force_N' column, coerce voltage to numeric, and compute forces from voltage when present; preserve previous behavior for 'force_N'. Raises clearer error if neither column exists.
